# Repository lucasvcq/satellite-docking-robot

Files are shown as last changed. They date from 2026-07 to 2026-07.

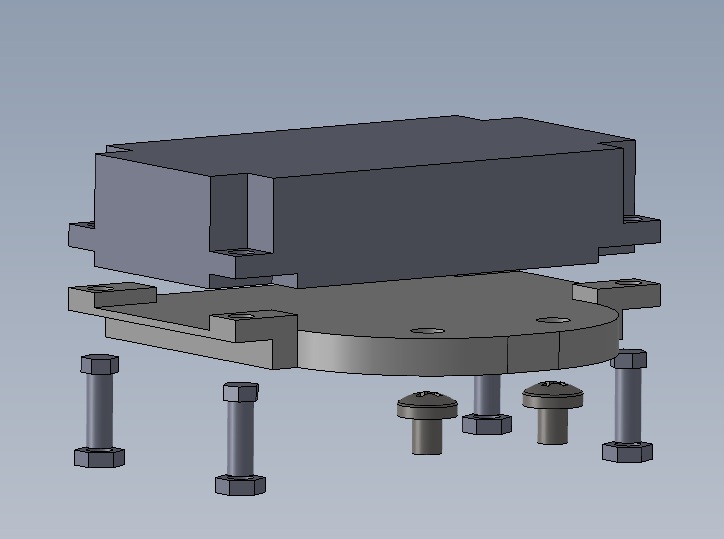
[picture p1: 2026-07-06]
Station Hote/Docking/Final/captures finales/assemblage_convertisseur_vueeclat.PNG

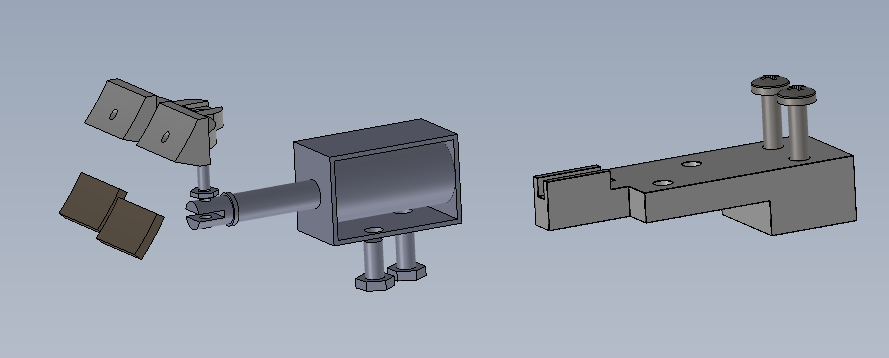
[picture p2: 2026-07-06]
Station Hote/Docking/Final/captures finales/assemblage_finale_vueeclat.PNG

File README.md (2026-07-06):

# Satellite Docking & Filming Robot

A two-part robotic system simulating satellite deployment, inspection, and re-docking — built as a 25-person, one-semester engineering project.

## Overview

The project reproduces a mechanism found on real satellites: a **fixed module** (simulating the main satellite) and a **mobile module** that ejects from it, films the fixed module from the outside using an onboard camera, and then autonomously re-docks.

Team of 25 students over one semester. I was responsible for the **entire software/electronics stack**: code, motor selection, battery selection, camera integration, and wiring.

## My Role

- Full embedded software (Arduino) controlling the mobile module's motors and camera
- Motor selection and sizing for the ejection/return mechanism
- Battery selection (capacity/weight tradeoff for the mobile module)
- Camera integration for the filming sequence
- Full wiring/harness design for the mobile module

## Tech Stack

- **Hardware:** Arduino
- **Domain:** Motor control, embedded C/C++, power budgeting, camera systems

## Key Technical Points

- Coordinating ejection, filming, and return in a single autonomous sequence
- Balancing battery weight vs. flight/operation time on the mobile module
- Wiring reliability on a moving, ejectable platform

## Demo

<!-- Add photos/video of the fixed + mobile module here -->

## Context

School project — ICAM, 2nd year engineering, group project (25 students, 1 semester).

> Note: source code comments, the full project report, and documentation are in French (school requirement). This README provides an English summary of the project.

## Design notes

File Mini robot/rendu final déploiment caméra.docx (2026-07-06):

Rendu final : Partie déploiement de la caméra

Nomenclature

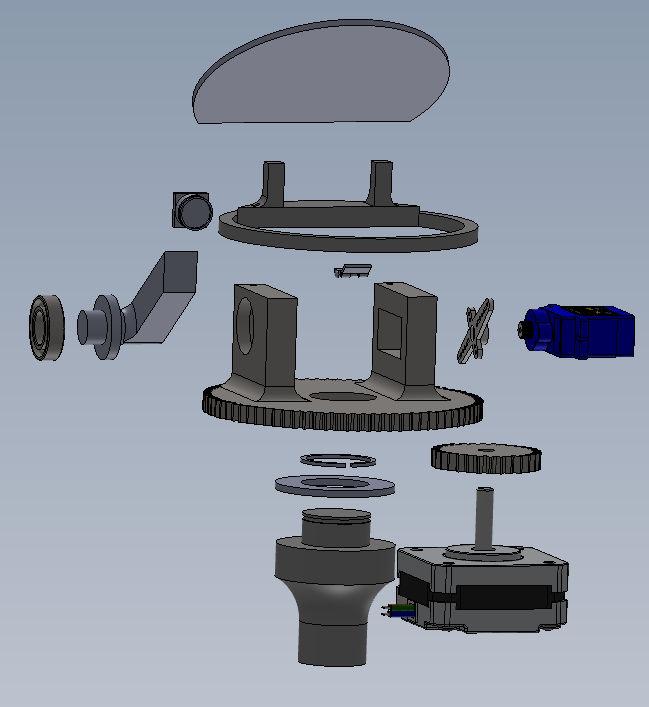
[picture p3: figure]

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
1: Axe chasis | 8 : Couvercle
2 : Roue | 9 : Charnière
3 : Pignon | 10 : Servo moteur
4 : Roulement à bille | 11 : Hélice servomoteur
5 : Caméra | 12 : Butté à aiguille
6 : Bras | 13 : Moteur pas à pas
7 : Support couvercle | 14 : Circlips

Gamme de montage :

Partie déploiement de la caméra
N° étape | Opérations (soudure, taraudage, …) | Schéma, croquis, solidworks

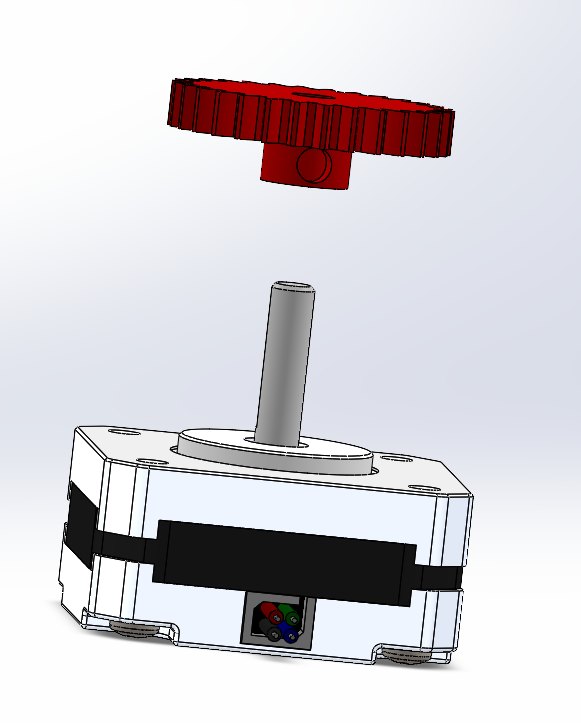
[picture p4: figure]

1 | Placer le pignon sur l’axe du moteur pas à pas

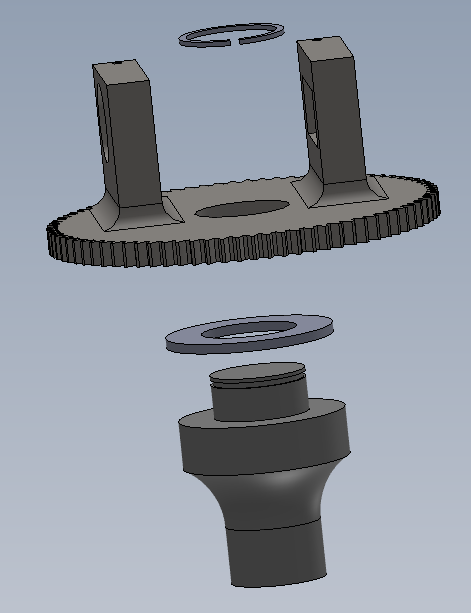
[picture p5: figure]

2 | Placer sur l’axe du châssis la butée à aiguille puis la roue et le circlips

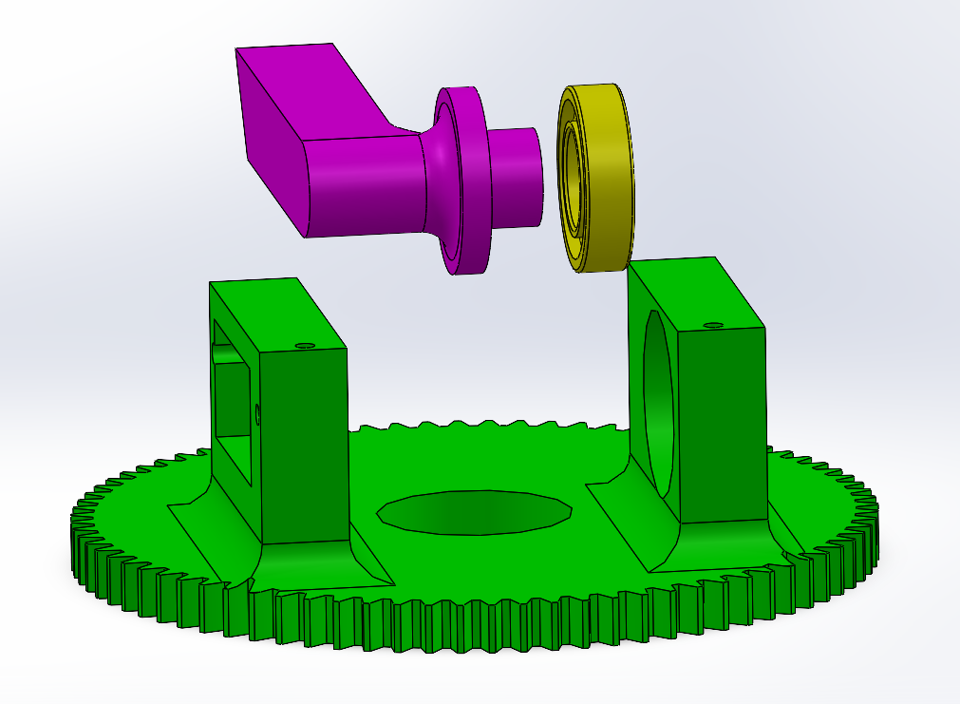
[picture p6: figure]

3 | Placer le roulement et le bras dans le premier socle de la roue | 1 2

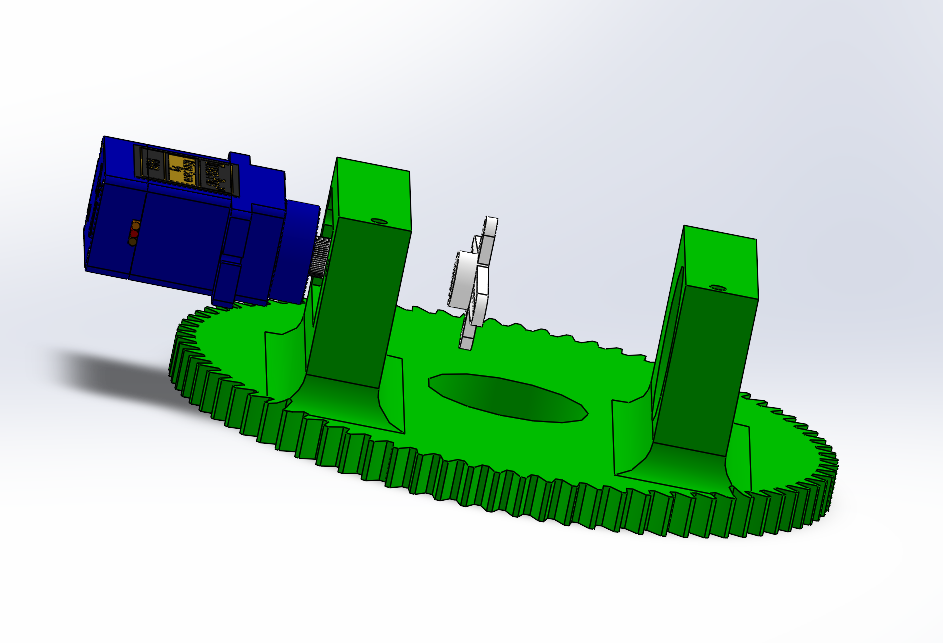
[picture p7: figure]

4 | Placer le servomoteur dans le second socle de la roue | 1 2

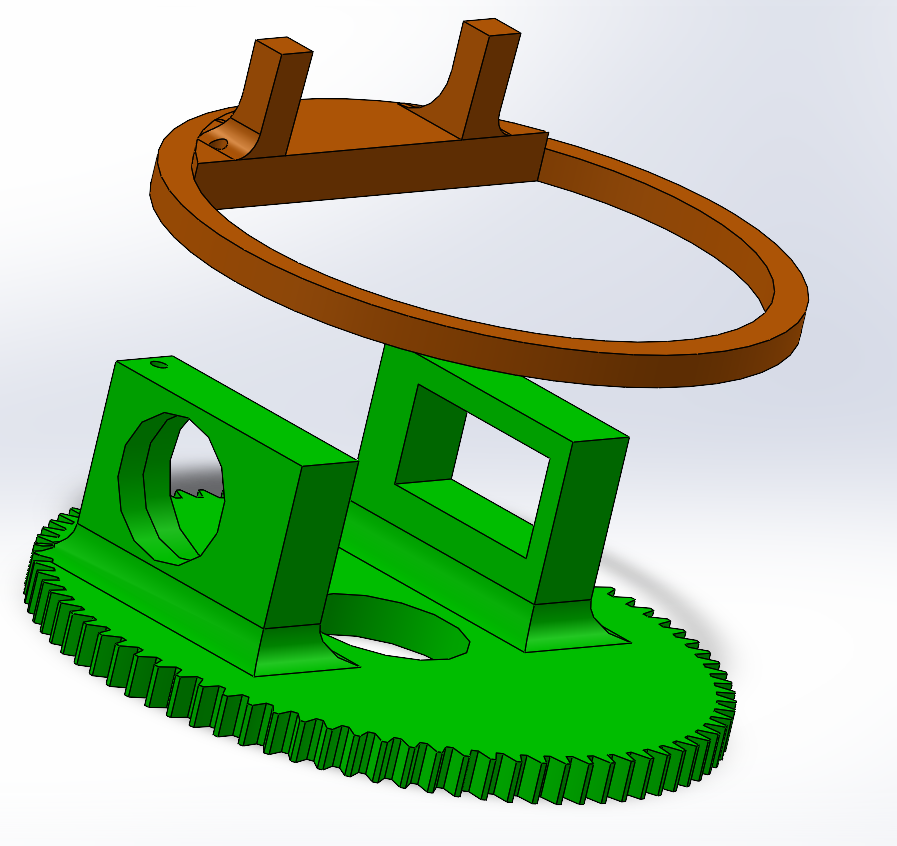
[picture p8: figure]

5 | Visser le support couvercle sur les socle de la roue de chaque côté avec deux vis M2

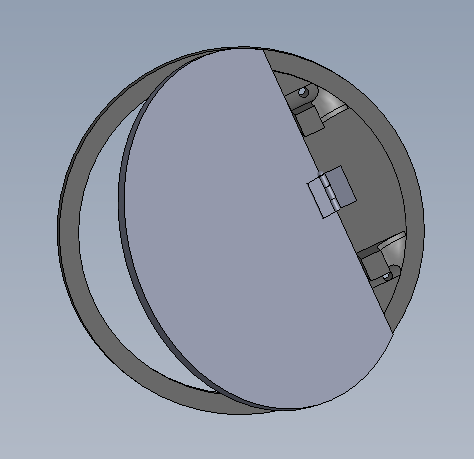
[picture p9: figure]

6 | Clouer la charnière entre les support clapet et le clapet afin d’avoir une liaison pivot

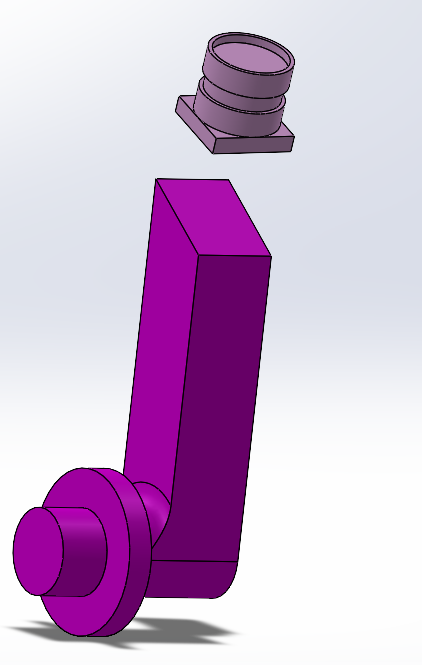
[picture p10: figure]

7 | Collé avec du scotch double face la caméra sur le bout du bras

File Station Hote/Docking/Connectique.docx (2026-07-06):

Fonctionnement :

La station hôte est branchée sur secteur et délivre une certaine énergie. Cette énergie doit être convertie en 12v pour alimenter deux électrodes en nickel qui sont reliés grâce à deux câbles électriques soudé à chacune des électrodes

Problème : comment gérer la connectique et convertir le courant électrique ?

=> Il faut aussi penser qu’il faut alimenter 5 moteurs qui sont sur la station mais eux ne dépendant pas de la batterie;

donc comment les alimenter ?

Ensuite une fois contact entre les 4 électrodes : que faire comme branchement pour que la batterie délivre son énergie aux 4 moteurs du mini robot ?

Est ce que l’on s’aide la carte arduino ?

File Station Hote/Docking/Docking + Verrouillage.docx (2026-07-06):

Docking + Verrouillage

Idées :

-S’inspirer des aspirateurs (aussi tondeuses) autonomes et de la phase de rangement dans leur base rechargeable (car verrouillage et rechargement)

-Même fonctionnement qu’un chargeur par induction magnétique ?

-Technologie QI =>a proximité de l'appareil et du support provoque un champ électromagnétique qui génère du courant

=>l’induction magnétique se produit grâce à une différence de potentiel électrique aux bornes d’un conducteur électrique, donnant naissance à un phénomène électrique

=>La recharge sans fil ou par induction repose sur la loi de l’induction de Faraday (https://fr.wikipedia.org/wiki/Loi_de_Lenz-Faraday) et la loi d’Ampère (https://fr.wikipedia.org/wiki/Th%C3%A9or%C3%A8me_d%27Amp%C3%A8re). Un courant qui circule dans une bobine génère un champ magnétique. On retrouve cette bobine dans la station de recharge. Ce champ magnétique produit une tension dans une deuxième bobine, qui se trouve dans l’appareil même. Cette tension rend possible la circulation du courant dans cette deuxième bobine.

Liens vidéos :

https://youtu.be/eUmNK34zg4w?si=RE0UxOJwnrwsriQn

Liens documents:

-pour la recharge par induction https://www.electronique-mag.com/article10755.html

-exemple de chargeur https://shop.aeg.fr/aspirateurs/aspirateurs-robots/accessoires/socle-de-chargement-du-robot-aspirateur-purei9-rx9-sans-adaptateur/p/4060000710

-mécanisme avec des lamelles de cuivre https://www.robot-maker.com/forum/topic/4003-robot-autonome-se-rechargeant-tout-seul/

-exemple de la brosse à dent https://d-krypton.fr/index.php/technologie/138-technologie/objets/brosse-a-dents/analyse-brosse-a-dents/526-principe-de-fonctionnement-du-chargement

-créer une batterie https://docs.wpilib.org/fr/latest/docs/hardware/hardware-basics/robot-battery.html

https://www.youtube.com/watch?v=eUmNK34zg4w&t=2s lien réparation chargeur aspirateur robot

-transmission d’energie sans fil https://www.youtube.com/watch?v=N0-TR-BpZpw

-lien sur le chargement par contact de charge https://www.vahle.de/fileadmin/cavok_upload/Energie%C3%BCbertragung/Ladekontakte/Ladekontakte/Franz%C3%B6sisch/Cat_10a_fr_Contacts_de_charge.pdf

https://www.youtube.com/watch?v=0F4qeJG9QhU

-dimensionner sa batterie lithium ion https://www.youtube.com/watch?v=PDcdBUG9SnE

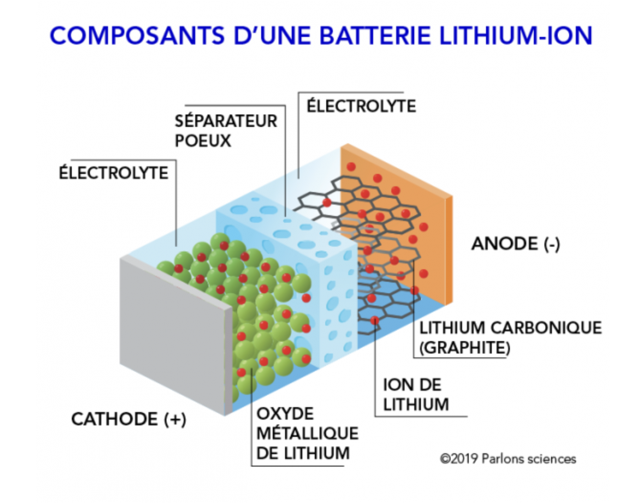
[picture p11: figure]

https://www.webmotoculture.com/station-de-charge-robot-tondeuse-husqvarna/16436-connecteur-charge-robot-tondeuse-husqvarna-group-588950902-7391736256667.html

https://www.webmotoculture.com/station-de-charge-robot-tondeuse-husqvarna/16406-plaque-connexion-charge-robot-tondeuse-husqvarna-574490003-7391736406284.html

https://www.amazon.fr/Lot-anodes-cuivre-pur-galvanoplastie/dp/B07PYNRYX3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

pas le zinc car oxydation donc dégradation de l’électrode

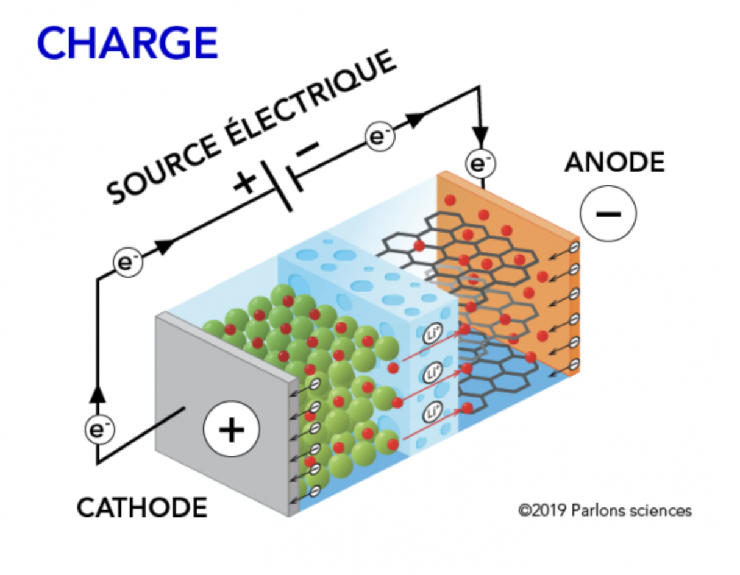
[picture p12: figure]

charge batterie lithium ion

https://passionelectronique.fr/charger-une-batterie-lithium-ion-cccv/#:~:text=Un%20courant%20de%201%2C5,si%20r%C3%A9p%C3%A9t%C3%A9%20dans%20le%20temps)

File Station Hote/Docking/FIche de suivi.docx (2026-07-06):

SUIVIS

Fiche de liens et description plus précise des idées : https://docs.google.com/document/d/11aIBwprFXZhD-TSYb-oCCpfROF9s-JA2nkJWaiH0Sx0/edit?usp=drive_link

DATES | TÂCHES FAITES | TÂCHES/IDÉES EN COURS | A FAIRE
19/12/2023 | -recherche sur quel mode de chargement -technologie qi -où le placer ? | -induction ? -système des robots tondeuses ou de maison | poursuivre les recherches sur le mécanisme de chargement
20/12/2023 | -recherche sur la recharge MIR -fonctionnement batterie lithium | -charger par champ magnétique avec du fil de cuivre mais problème sur le poids donc faire un chargement par contact entre électrode | poursuivre les recherches sur le mécanisme de chargement

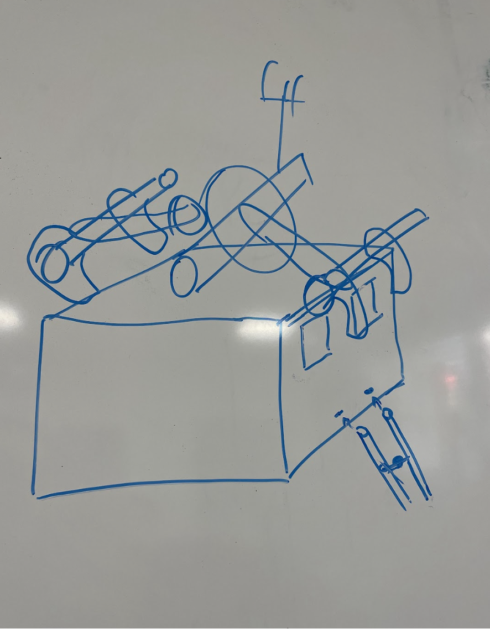
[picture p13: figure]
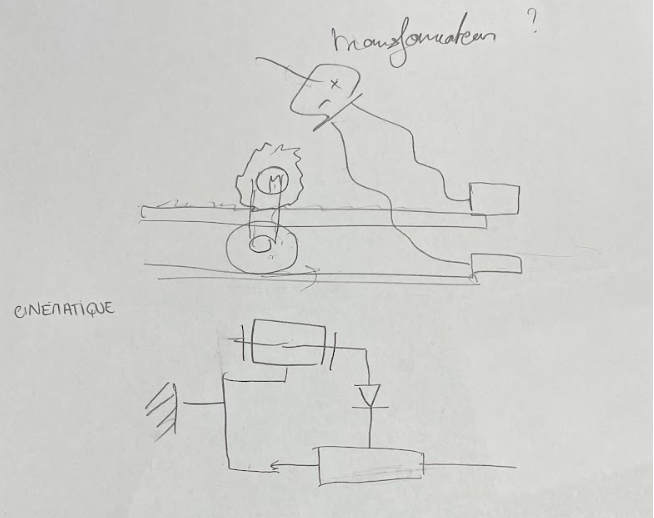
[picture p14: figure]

17/01/2024 | -recherche sur les batteries au nickel - besoin d’un transformateur | -la charge s’enclenche en même temps que le verrouillage par système de pignon crémaillère alimenté par un moteur pas à pas - seconde méthode : par un ressort lié aux pinces | -schéma cinématique du mécanisme - calculer quel type de transformateur utilisé -calculer la pression à appliquer sur les plaques de nickel -calcul du couple moteur nécessaire
24/01/2024 | -début de la rédaction pour la jalon avec les avantages et les inconvénients de toutes les solutions qui ont pu être envisagées https://docs.google.com/document/d/1Y-hJFDyKSYLCWOa0ryIylMQf1yoepxAHz28kI_ejrlM/edit?usp=drive_link | -réalisation de tous les schémas cinématiques pour les différentes solutions | -poursuivre les recherches - calculer quel type de transformateur utilisé -calculer la pression à appliquer sur les plaques de nickel -calcul du couple moteur nécessaire -continuer la rédaction -mettre au propre les schémas
31/01/2024 | -poursuite de la rédaction du jalon | -finir les schémas + continuer de s’informer https://knowhow.distrelec.com/fr/automatisation/alimentation-et-mouvement-des-robots-comment-fonctionnent-les-robots/ | -terminer l’écriture du jalon -commencer le solidwork
28/02 | choix du solénoïde à commander + calculs avec la partie commande Idée : mettre un isolant au bout de la tige du solénoïde, dont l’épaisseur diminue facilement afin que le moteur ne subisse pas de force de pression + impression d’une pièce en PLA pour renforcer l’isolation et protéger la tige | -solidworks du solénoïde + écriture du jalon 2 | -poursuivre l'écriture du jalon 2 + finir solidworks + commander les matériaux
04/03 | solidworks + récap avec mr rodriguez | solidworks + connectique | solidworks + choix de l’isolant et des électrodes
06/03

Lucas RODRIGUEZ Noémie HEMAR

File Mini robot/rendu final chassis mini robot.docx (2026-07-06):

Présentation Générale:

Contexte

Depuis plusieurs années, les classes préparatoires PT de l’ICAM Toulouse réalisent un projet

durant le second semestre. Le but de ce projet étant de mettre en pratique toutes les compétences

pratiques et théoriques étudiées pendant ces 2 ans. L’objectif de cette année 2024 est de réaliser et

d’automatiser un robot spatial télépiloté. Celui-ci sera composé d’une station hôte et d’un mini robot

qui sera capable de filmer un satellite dans l’espace.

Le projet a été lancé le 19 décembre 2023, il s'accompagnera de différents jalons et s'achèvera par une

présentation orale le 31 mai 2023.

b) Objectifs du projet

L’objectif principal de ce projet est de créer un robot capable de réaliser une vidéo de son

satellite afin d’y diagnostiquer les éventuels dommages. Les images produites pourront être utilisées

pour des projets extérieurs.

Le robot devra respecter un cahier des charges précis et devra s’adapter à toutes ses contraintes

environnementales et économiques.

Ce projet permet une étude de dimensionnement, de conception, de réalisation et

d'automatisation, il concrétise l’ensemble de nos connaissances théoriques et nous permet d’avoir une

meilleure vision du métier d’ingénieur.

Le jalon 1 a pour objectif de reprendre l’ensemble du travail réalisé lors de ces premières semaines et

notamment de détailler les solutions envisagées et retenues pour chaque sous-partie.

c) Cahier des charges

Dans le cadre de notre projet, l’espace sera modélisé par une plaque de téflon.

Ce mini robot SPACE INSPECTOR sera composé de deux modules :

- La station hôte

- Le mini robot

Ses actions seront les suivantes:

Le mini-robot s'éjecte de la station, il glisse sur la plaque, réalise ses différents plans et retourne à la

station. Il se verrouille et se recharge jusqu’à sa prochaine utilisation.

Icam, site de Toulouse 75 avenue de Grande Bretagne CS 97615 31300

Toulouse cedex 3

+33 5 34 50 50 50 icam.fr SIRET 399 252 154 000

48

Enseignement supérieur et recherche | Services aux entreprises | Formation professionnelle

3

Le mini-robot sera relié à sa station hôte grâce à un câble (fil d'Ariane) d’une longueur de 1,5 à 2 mètres,

ceci pour assurer sa sécurité et pour ne pas endommager le satellite.

Station hôte

La station hôte ne doit pas dépasser les dimensions maximales d’un cube d'arête 10 pouces c’est à dire

de 25,4 cm.

Elle contiendra le mini robot pendant la phase de décollage et sera composée d’un treuil qui permettra

son retour ainsi que d'un système de verrouillage et de déverrouillage.

Mini-robot

Le mini-robot est considéré comme le corps du robot, il devra se ranger dans sa station hôte lors du

décollage et à la fin de chaque prise de vue. Il se compose d’une caméra capable de se ranger

entièrement et de se déployer à chaque utilisation. La masse du robot ne doit pas excéder 1,5 kg.

Icam, site de Toulouse 75 avenue de Grande Bretagne CS 97615 31300

Toulouse cedex 3

+33 5 34 50 50 50 icam.fr SIRET 399 252 154 000

48

Enseignement supérieur et recherche | Services aux entreprises | Formation professionnelle

4

d) Organisation générale

Pour réaliser ce projet notre promotion a été répartie en quatre groupes suivant sa classe et son

ordre alphabétique. Nous sommes le groupe PTB-B.

Dans notre groupe, les différents élèves ont été répartis ainsi: certains s’occupent de la partie mini-

robot, d’autres de la station hôte et ceux qui restent de l’électronique ( docking et commande).

La répartition générale du groupe a été faite par nos professeurs. Deux chefs de projets ainsi que deux

chefs de partie ont été désignés : l’un pour le mini robot et l’autre pour la station hôte. Chaque membre

du groupe a été rattaché à une sous-partie en fonction de ses compétences.

D’un point de vue organisation, nous avons fait le choix de mettre en place des fiches de suivi par sous-

partie. A chaque fin de séance, chaque groupe énumère ce qu’il a fait durant la séance, ce qu’il ont

commencé à faire et ce qu’il prévoit de faire pour les prochaines séances. De cette manière les chefs ont

une trace du travail de chacun.

Nous avons également désigné un chef de salle, un chef d’imprimante et un chef d’achat.

Le budget maximal pour ce projet s'élève à 500 euros.

Mini robot

1/ Présentation partie et cahier des charges:

Le mini robot doit être pris en compte dans la station hôte pour se recharger et aura la mission de prendre des prises de vue pour permettre le transfert d’image vers la Terre. Ses dimensions devront donc correspondre à celles de la station hôte en ayant un poids le plus restreint possible afin que celui- ci puisse s'éjecter . Équipé d'une caméra, il pourra déployer cette dernière via une commande au sol utilisant un joystick.

La masse totale du mini robot (hors station hôte, câble et treuil) ne devra pas dépasser 1,5 kg. De plus, il reste toujours attaché à la station hôte par un câble, permettant de le ramener à l'aide d'un treuil.

Les principales exigences que nous nous sommes fixées pour le mini robot sont la solidité, la facilité de fabrication et enfin un mini robot peu onéreux.

Tout d’abord, la première idée, pour la conception de ce mini robot, était de prendre des plaques que l’on allait fixer ensemble afin de former un parallélépipède rectangle de hauteur 10 cm, de longueur 15 cm et de largeur 12 cm. Cependant après avoir discuté avec les chefs de projet, nous en avons conclu qu’il y allait avoir de grandes chances que celui-ci ne puisse pas se loger dans la station hôte à cause de sa forme rectangulaire, et qu’il suffirait d’un simple décalage lors de sa phase de treuillage pour bloquer tout le système.

C’est pour cela que nous avons choisi une autre solution, que nous allons vous détailler ci-dessous.

2/ Solution retenue + mise en place

-châssis:

Premièrement, à la suite de plusieurs idées de conception, en prenant les avantages de chaque solutions, et bien sur en regardant les inconvénients, nous avons décidé de réaliser notre mini robot sur un point primordial, la facilité d'insertion du mini robot dans la station hôte, qui sera essentiel pour le fonctionnement du système global

C’est pour cela que nous avons choisi de réaliser une forme cylindrique avec une tête sphérique qui se limite à ces dimensions : hauteur : 10 cm, de longueur 15 cm et de largeur : 12 cm.

Nous avons simplifié au maximum le châssis en le conservant en une seule pièce, que l’on séparera ensuite en deux parties, pour avoir une difficulté de conception et d’assemblage moins importante.

De plus ce châssis sera modelé en fonction des systèmes qu’il accueillera, avec la création de support depuis le châssis, pour fixer chacun de ses composants

Ensuite, pour refermer le mini robot, nous allons attacher son toit avec une mise en position(MIP) grâce à leurs faces et un maintien en position (MAP) grâce à deux vices et deux écrous.

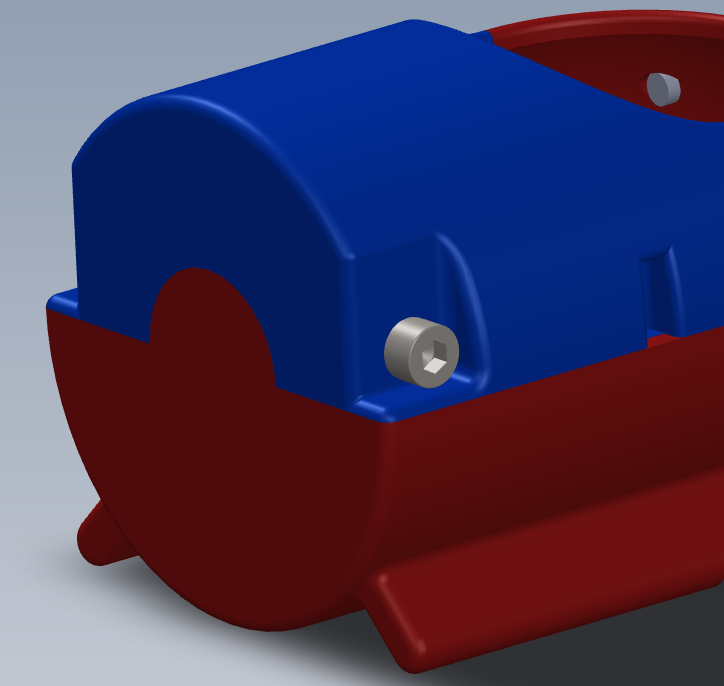
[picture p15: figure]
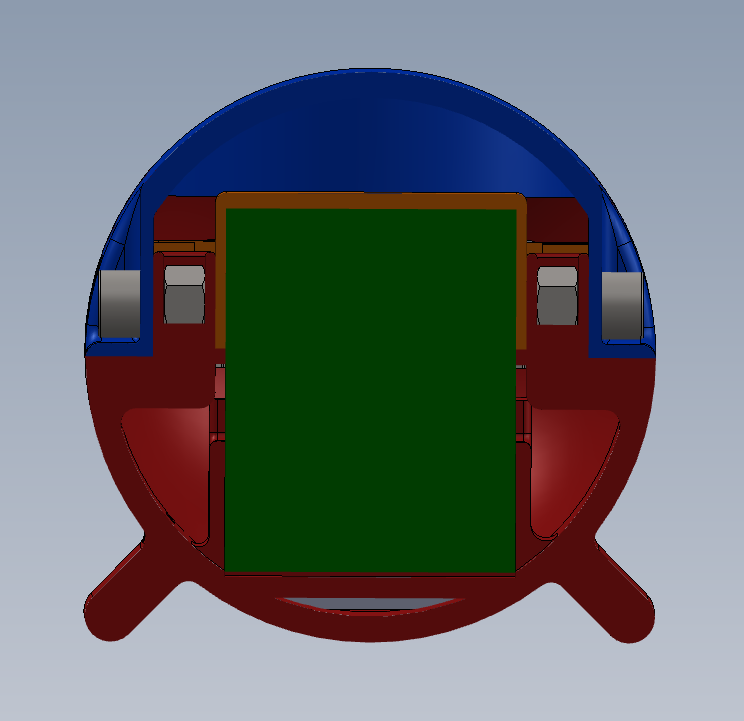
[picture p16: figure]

-Les Matériaux utilisés :

Nous avons réalisé toutes nos différentes pièces, que ce soit la base de notre châssis ou encore les différents supports, à l'imprimante 3D avec le filament de type PLA. Ce matériau assurera la résistance de notre mini robot et nous permettra de facilement usiner notre solution.

Ensuite, concernant les vis nous avons utilisé des vis M3 pour fixer tous nos différents supports, puis des vis M8 pour fixer le toit de notre mini robot à sa base. Puis pour assurer une bonne fixation nous avons rajouté des écrous de taille M3 ou M8

## -Modèle du châssis extérieur pour la structure complète du robot :

Dans notre solution, nous retrouvons deux encoches qu’ils maintiennent le mini robot lors de son entrée dans la station hôte. Puis, nous avons trois pions dans lesquels nous allons enrouler le câble du treuil, puis que nous allons encastrer sur la face droite de notre mini robot permettant d’avoir une bonne prise de celui-ci. Sur le côté, nous avons l’emplacement des deux électrodes qui peut alimenter le système et permettent au mini robot de se recharger. Ensuite nous retrouvons deux patins sur la partie inférieure du châssis afin de le stabiliser et cela facilitera le glissement.

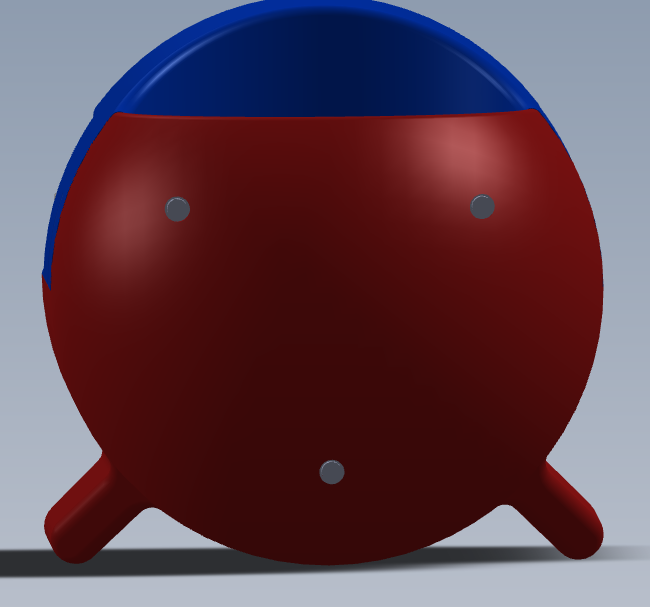
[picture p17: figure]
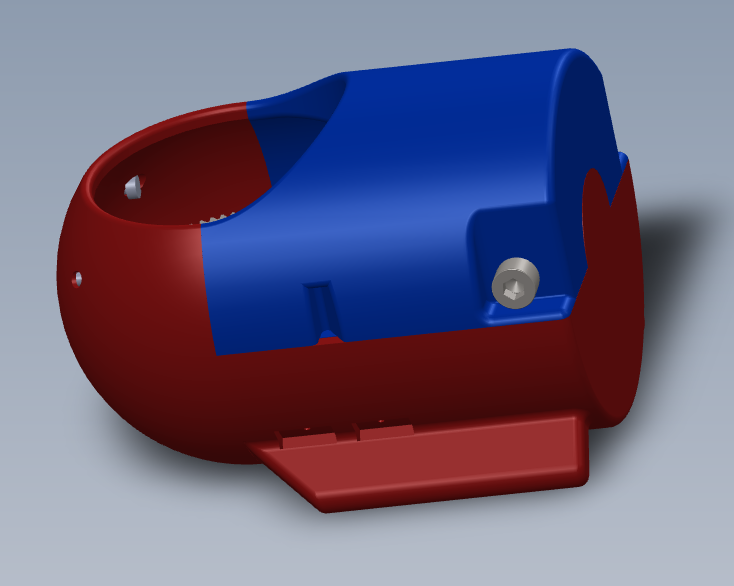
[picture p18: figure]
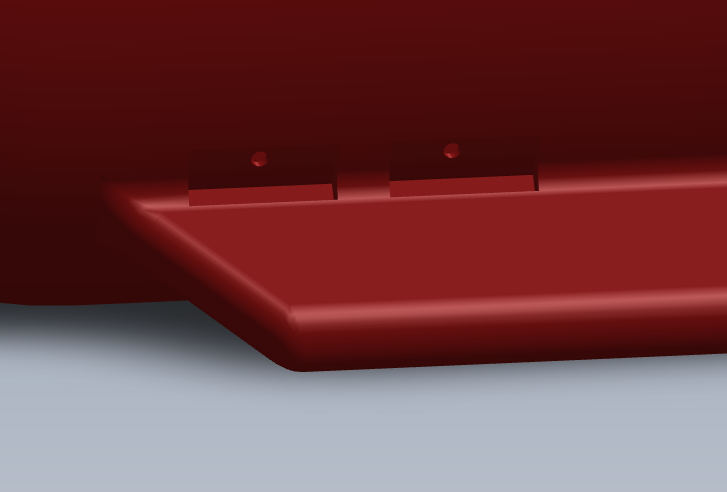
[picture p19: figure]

## -Ouverture:

Ensuite, concernant l’ouverture du châssis haut nous avons réalisé, à l'imprimante 3D, un clapet anti retour en forme de cercle de diamètre 8 cm. Il permet de protéger la caméra tout en réduisant le poids et sera facile à installer. Pour réaliser le basculement du couvercle nous avons simplement visser une charnière, comme vous pouvez le voir ci-dessous.La caméra, lors de son déploiement, poussera le clapet qui se lèvera et lors de son rangement il se baissera tout seul. Lors du déploiement la caméra poussera le clapet lui offrant une grande vision, puis lors de son rangement le clapet se refermera tout seul.

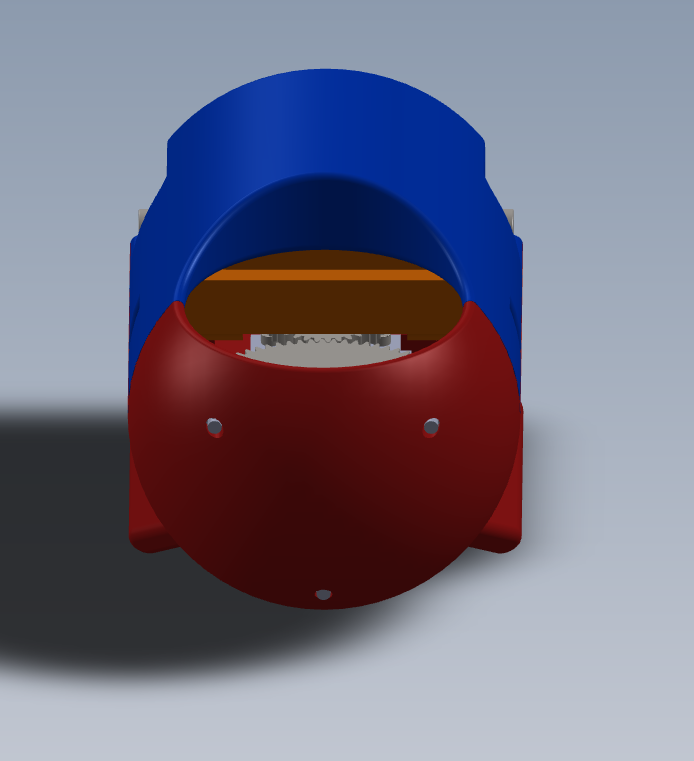
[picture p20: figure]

-Modèle du châssis intérieur pour la structure complète :

Dans notre solution, nous avons le module esp32 de la caméra, la carte de prototypage qui contrôle les différents moteurs, puis,le système de déploiement de la caméra et la batterie. Nous retrouverons aussi tous les différents supports qui viendront maintenir ces composants.

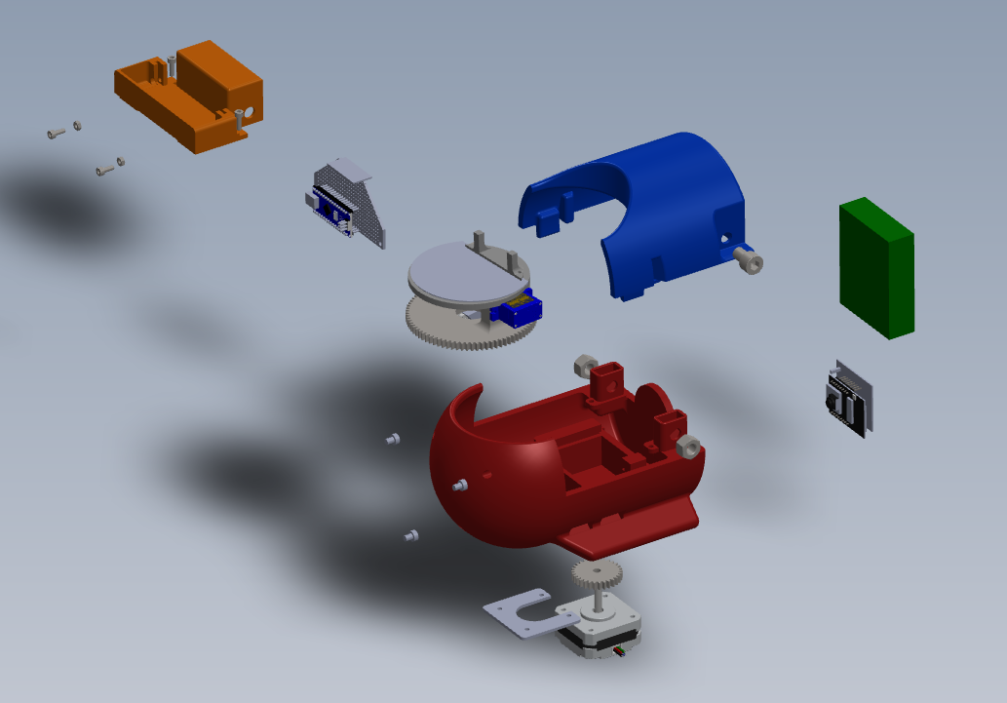
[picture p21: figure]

3/ Problèmes rencontrés et solutions

Avantages : Cette structure serait très facile à assembler et solide car elle est seulement composée que de deux pièces. De plus, cette solution n’aura aucun problème pour rentrer dans la station hôte grâce à sa tête sphérique.

Inconvénients : L'inconvénient principale de cette solution est qu'elle ne permet pas de faire des modifications s' il y a des soucis lors de la conception car nous avons une place très restreinte à l'intérieur du mini robot. En plus de cela, elle va demander un temps de fabrication assez conséquent.

Problèmes et solutions :

- réussir à faire rentrer tous les composants dans le mini robot
- diminuer au maximum la taille du mini robot afin qu’il puisse se loger dans la station hôte
- Nous avons mis au début un seul anneau sur la face avant du mini robot mais nous avons vu à l'aide de test que le robot, lors de la traction du treuil, se balançait et pourrait bloquer sa rentrée dans la station hôte. C’est pourquoi nous avons pensé à mettre en place le système avec trois pion afin d’avoir un bonne prise du mini robot
- nous avons eu des problèmes avec les cables car nous avons vu que avec la carte de prototypage et la caméra il fallait trouver une place pour les faire passer dans notre mini ronot

Solution générale:

En conclusion nous avons passé beaucoup de temps sur solidworks à modifier la tailles des différents composants afin que tout puisse se loger dans le mini robot. Nous avons très vite eu l’idée eu l’idée de faire de faire une première impression du châssis du mini robot, afin d’identifier les différents problèmes de conception du à ça taille très restreinte, ce qui nous a permis d’avancer pas à pas en modifiant les pièces au fur et mesure pour que tout s’imbriquent parfaitement et en gagnant le maximum de place.

Autres:

-Schéma cinématique mini robot:

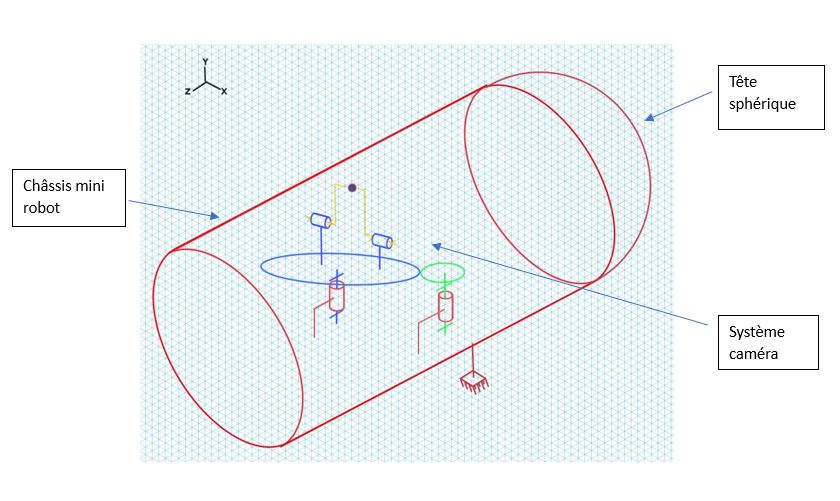
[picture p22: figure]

-Gamme de montage :

N° étape | Opérations (soudure, taraudage, …) | Schéma, croquis, solidworks

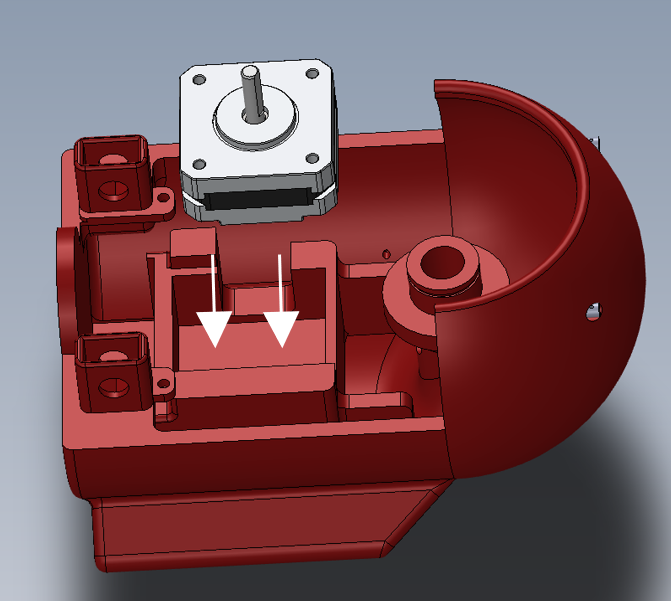
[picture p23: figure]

1 | Prendre la partie bas du châssis et placer le moteur pas à pas dans son emplacement

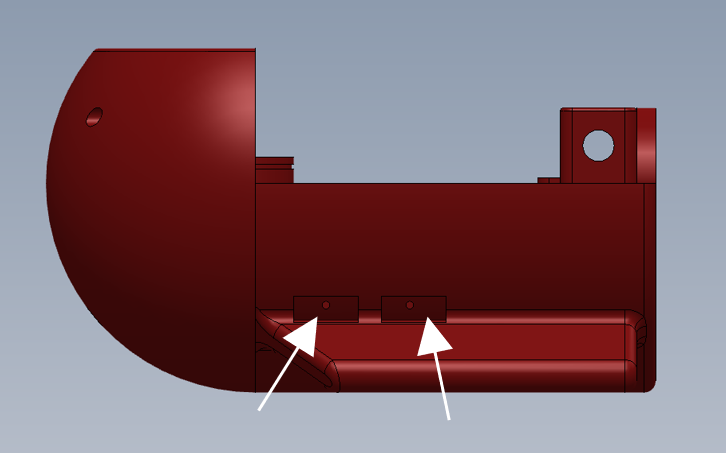
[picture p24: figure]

2 | Placer les électrodes à leurs places respectives

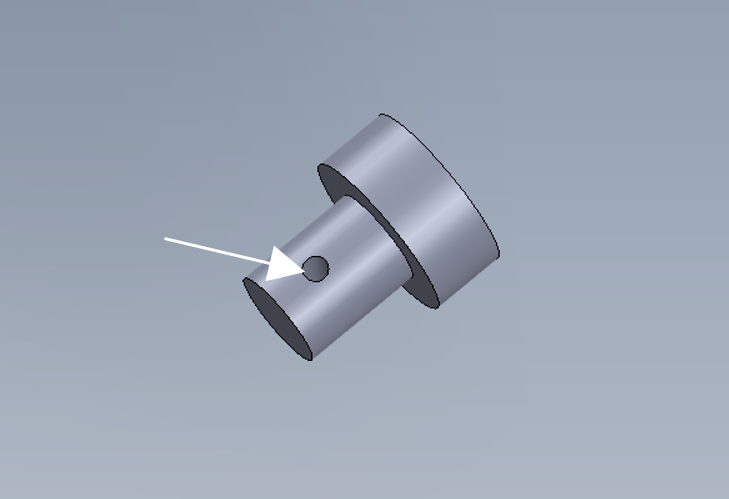
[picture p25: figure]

3 | Prendre le fil du treuil et faire un noeud autour de chaques pions
4 | Encastrer les 3 anneaux,directement dans le châssis

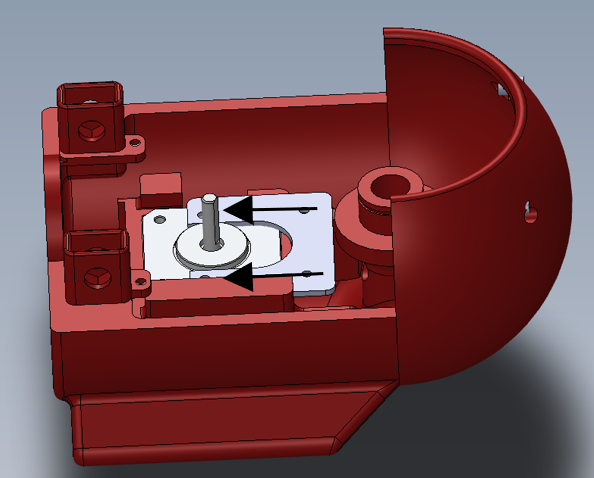
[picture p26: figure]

5 | Placer la plaque qui viendra bloquer le moteur pas à pas et la visser avec 4 vis de diamètre 3 mm


6 | Visser la plaque avec 4 vis de diamètre 3 mm


7 | Placer le module esp 32 de la caméra avec son support


8 | Placer le pignon sur l’axe du moteur pas à pas


9 | Placer le système de caméra sur l’axe du châssis


10 | Mettre la batterie à son emplacement


14 | Visser son couvercle avec deux vis de diamètre 3 mm et de deux écrous


12 | Insérer la carte de prototypage


13 | Verrouiller la carte à l’aide de deux vis de diamètre 3 mm et de deux écrous


14 | Placer le châssis haut sur le châssis bas afin de fermer le robot la visser avec deux vis de diamètre 8 mm et ses boulons

Nomenclature :


1: châssis bas | 7 : Batterie
2 : châssis haut | 8 : carte de prototypage
3 : moteur pas à pas | 9 : support carte de prototypage
4 : plaque (support moteur) | 10 : module caméra esp32 avec son support
5 : pignon | 11 : pions
6 : système caméra

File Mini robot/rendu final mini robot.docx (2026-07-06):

rendu final mini robot

nomenclature:

Gamme de montage :

Partie mini robot
N° étape | Opérations (soudure, taraudage, …) | Schéma, croquis, solidworks


1 | Prendre la partie bas du châssis et placer le moteur pas à pas dans son emplacement


2 | Placer le pignon sur l’axe du moteur pas à pas


3 | Placer sur l’axe avec un épaulement du châssis bas la butée à aiguille puis la roue et le circlips


4 | Placer le roulement et le bras dans le premier socle de la roue | 1 2


5 | Placer le servomoteur dans le second socle de la roue | 1 2


6 | Visser le support couvercle sur les socle de la roue de chaque côté avec deux vis de diamètre M2


7 | Clouer la charnière entre les support clapet et le clapet afin d’avoir une liaison pivot


8 | Collé avec du scotch double face la caméra sur le bout du bras


9 | mettre la batterie puis visser son couvercle avec deux vis de diamètre 4 mm
10 | insérer la carte de prototypages
11 | placer le cache de la plaque de prototypage afin de protéger les câbles


12 | placer le châssis haut sur le châssis bas afin de fermer le robot la visser avec deux vis de diamètre 6 mm et ses boulons
13 | placer les deux électrodes


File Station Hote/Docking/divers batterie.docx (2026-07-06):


choix d’electrodes


https://fr.aliexpress.com/item/1005005652738294.html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,scm-url:1007.40000.327270.0,pvid:93ebbf17-09de-4c7a-8013-ba4026c8d7f2,tpp_buckets:668%232846%238111%231996&pdp_npi=4%40dis%21EUR%212.90%210.49%21%21%2122.12%213.73%21%40211b617a17069785410205563ed12e%2112000033895913581%21rec%21FR%21%21AB&utparam-url=scene%3ApcDetailTopMoreOtherSeller%7Cquery_from%3A&search_p4p_id=202402030842210684180786807887908647_2

isolant


https://fr.aliexpress.com/item/1005005850378507.html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,scm-url:1007.40000.326746.0,pvid:3229bbeb-f918-4b03-a76d-1be9c16ab99a,tpp_buckets:668%232846%238111%23472&pdp_npi=4%40dis%21EUR%211.71%210.49%21%21%211.82%210.53%21%402103854017069791498925819e0110%2112000034570935919%21rec%21FR%21%21AB&utparam-url=scene%3ApcDetailBottomMoreOtherSeller%7Cquery_from%3A

https://floordirekt.fr/products/gummiplatten-aus-sbr-gummi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

OK https://www.amazon.fr/ACIT-n%C3%A9opr%C3%A8ne-caoutchouc-polyur%C3%A9thane-%C3%A9paisseur/dp/B0BBRPN3B2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

OK

https://www.amazon.fr/Lot-anodes-cuivre-pur-galvanoplastie/dp/B07PYNRYX3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

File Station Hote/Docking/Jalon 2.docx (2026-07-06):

La solution finale choisie est la recharge par contact entre électrodes conductrices. Le matériau privilégié est le cuivre car il possède le meilleur rendement coût-efficacité.

Par rapport aux autres systèmes choisis, nous devons éviter que les électrodes gênent le système d'éjection du robot. Pour cela nous avons réfléchi à deux solutions.

Afin d’effectuer le contact entre les électrodes placées sur le mini-robot et les deux autres présentes sur la station hôte, nous avions tout d’abord pensé à la création d’un système pignon crémaillère. Celui-ci aurait été alimenté par un moteur pas à pas par exemple. Les électrodes seraient donc placées sur le système et bougeraient en avançant le long de la crémaillère. Le moteur et le courant transmis par les électrodes seraient alors alimentés par la batterie.


x

y

z

Cependant cette idée à rapidement été abandonnée car elle est complexe à réaliser, énergivore et prendrait trop de place inutilement au sein de la station hôte.

En restant sur le principe de pouvoir approcher et écarter les électrodes pour que le contact déclenchant le chargement soit créé, une seconde solution a été envisagée : mettre un moteur solénoïde. Ce petit moteur réalise une simple translation de 8 mm de course. Il ne prend pas beaucoup de place et ne consomme pas beaucoup d’énergie lors de son fonctionnement. Les deux électrodes sont placées à l’extrémité de son axe et la charge est dépendante de l’enclenchement de la translation. Il y aurait donc deux électrodes + , - , placées sur une même face latérale du mini-robot afin que nous puissions nous servir seulement d'un moteur solénoïde. Pour la réalisation de l’assemblage du robot, nous les avons modélisés sur solidworks ainsi que tout le système de charge.

- Moteur solénoïde


Ci-dessus se trouve le moteur solénoïde. Étant donné que nous allons l’acheter, le mécanisme de translation a été représenté de manière grossière mais toutes les cotes et éléments clés ont été dessinés. On remarque que dans la cage du moteur, 2 trous taraudés sont déjà présents ce qui nous permettras de plus facilement fixer le moteur à la station. De plus, l’axe est percé et il y a un espace pour insérer une éventuelle pièce. Nous avons profité de cet espace pour créer un support capable de venir se glisser à travers cette fente, et de réaliser le maintien des électrodes.

Plusieurs modélisations ont été faites :

- Première conception du support pour les électrodes :


Nous avons choisi d’utiliser la géométrie de l’axe du moteur solénoïde car il nous offre une très bonne solution pour emboîter notre support. Dans un premier temps, nous avons créé un capuchon qui viendrait se mettre dans l’encoche de l’axe du moteur puis à l’aide d’une goupille, nous le bloquons sur celui-ci. Nous avons réduit les surfaces des parties de gauche et de droite par souci de gâchis de matière. Mais, la création de ce capuchon gêne dans l’usage des trous déjà présents (soucis d'alignement parfait des trous qui est trop complexe à réaliser suite aux imprécisions de l'imprimante et de l'usinage).

- Deuxième conception du support pour les électrodes :


Nous avons donc décidé de choisir cette représentation finale pour notre support des électrodes. Nous avons enlevé le cylindre qui allait causer des soucis d’usinage mais nous avons laissé “le pavé” avec le trou qui permettra l’assemblage des deux pièces. Nous avons aussi annulé l’enlèvement de matière pour ajouter de la solidité car le gâchis potentiel reste moins important que la solidité de notre pièce. La matière utilisée est du plastique PLA, utilisé dans nos imprimantes 3D, et qui permettrait aussi d’isoler le moteur de tout courant électrique.

- Assemblage final :


Cuivre Isolant

Cette conception finale semble être la plus adaptée. Nous avons réussi à enlever un maximum de matière tout en conservant la solidité grâce à l'élimination des angles droit. On a aussi modélisé deux électrodes de cuivre et un isolant d’une épaisseur d'environ 3 mm qui servirait à réduire la force exercée par le moteur. En effet, lorsque le contact entre une électrode du mini-robot et une électrode de la station est fait, il ne faut pas que la pression exercée soit trop importante sous peine d'abîmer tout le mécanisme.

De plus, l’utilisation d’isolant semble être importante au sein du robot. En effet, la station hôte étant faite majoritairement en profilé aluminium nous voulons éviter tout possible court-circuit.

Au niveau du choix de la batterie, les recherches ont été effectuées en travaillant avec la partie commande. Il se sont chargés des calculs de dimensionnement et nous, de la connectique afin de savoir si le modèle se rechargeait plus ou moins facilement. A ce stade du projet, le modèle envisagé pour assurer l’autonomie du mini-robot est celui ci : modèle Accu Li-Ion MGL9073


L’avantage de ce modèle est qu’il n’est pas très lourd (143 g) et est de dimension acceptable (70x56x19mm). Elle sera positionnée sur l'arrière du mini-robot et, étant certainement le poids lourd du mini-robot, elle sera positionnée le plus proche du sol possible.

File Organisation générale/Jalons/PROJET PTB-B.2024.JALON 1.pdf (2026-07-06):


Icam, site de Toulouse | 75 avenue de Grande Bretagne | CS 97615 | 31300
Toulouse cedex 3
+33 5 34 50 50 50 | icam.fr | SIRET 399 252 154 000
Enseignement supérieur et recherche | Services aux entreprises | Formation professionnelle
Projet ICAM PTB-B | 2023-2024

# Jalon 1

# Projet Space Inspector

Icam, site de Toulouse | 75 avenue de Grande Bretagne | CS 97615 | 31300
Toulouse cedex 3

1

## SOMMAIRE

Icam, site de Toulouse | 75 avenue de Grande Bretagne | CS 97615 | 31300

2

# I) Présentation Générale:

### a) Contexte

Depuis plusieurs années, les classes préparatoires PT de l’ICAM Toulouse réalisent un projet durant le second semestre. Le but de ce projet étant de mettre en pratique toutes les compétences pratiques et théoriques étudiées pendant ces 2 ans. L’objectif de cette année 2024 est de réaliser et d’automatiser un robot spatial télépiloté. Celui-ci sera composé d’une station hôte et d’un mini robot qui sera capable de filmer un satellite dans l’espace.

Le projet a été lancé le 19 décembre 2023, il s'accompagnera de différents jalons et s'achèvera par une présentation orale le 31 mai 2023.

### b) Objectifs du projet

L’objectif principal de ce projet est de créer un robot capable de réaliser une vidéo de son satellite afin d’y diagnostiquer les éventuels dommages. Les images produites pourront être utilisées pour des projets extérieurs.
Le robot devra respecter un cahier des charges précis et devra s’adapter à toutes ses contraintes environnementales et économiques.
Ce projet permet une étude de dimensionnement, de conception, de réalisation et d'automatisation, il concrétise l’ensemble de nos connaissances théoriques et nous permet d’avoir une meilleure vision du métier d’ingénieur.
Le jalon 1 a pour objectif de reprendre l’ensemble du travail réalisé lors de ces premières semaines et notamment de détailler les solutions envisagées et retenues pour chaque sous-partie.

### c) Cahier des charges

Dans le cadre de notre projet, l’espace sera modélisé par une plaque de téflon.

Ce mini robot SPACE INSPECTOR sera composé de deux modules :
- La station hôte
- Le mini robot

Ses actions seront les suivantes:

Le mini-robot s'éjecte de la station, il glisse sur la plaque, réalise ses différents plans et retourne à la station. Il se verrouille et se recharge jusqu’à sa prochaine utilisation.


Icam, site de Toulouse | 75 avenue de Grande Bretagne | CS 97615 | 31300

3

Le mini-robot sera relié à sa station hôte grâce à un câble (fil d'Ariane) d’une longueur de 1,5 à 2 mètres, ceci pour assurer sa sécurité et pour ne pas endommager le satellite.

Station hôte

La station hôte ne doit pas dépasser les dimensions maximales d’un cube d'arête 10 pouces c’est à dire de 25,4 cm.

Elle contiendra le mini robot pendant la phase de décollage et sera composée d’un treuil qui permettra son retour ainsi que d'un système de verrouillage et de déverrouillage.

Mini-robot

Le mini-robot est considéré comme le corps du robot, il devra se ranger dans sa station hôte lors du décollage et à la fin de chaque prise de vue. Il se compose d’une caméra capable de se ranger entièrement et de se déployer à chaque utilisation. La masse du robot ne doit pas excéder 1,5 kg.

Icam, site de Toulouse | 75 avenue de Grande Bretagne | CS 97615 | 31300

4

### d) Organisation générale

Pour réaliser ce projet notre promotion a été répartie en quatre groupes suivant sa classe et son ordre alphabétique. Nous sommes le groupe PTB-B.
Dans notre groupe, les différents élèves ont été répartis ainsi: certains s’occupent de la partie mini-robot, d’autres de la station hôte et ceux qui restent de l’électronique ( docking et commande).

La répartition générale du groupe a été faite par nos professeurs. Deux chefs de projets ainsi que deux chefs de partie ont été désignés : l’un pour le mini robot et l’autre pour la station hôte. Chaque membre du groupe a été rattaché à une sous-partie en fonction de ses compétences.

D’un point de vue organisation, nous avons fait le choix de mettre en place des fiches de suivi par sous-partie. A chaque fin de séance, chaque groupe énumère ce qu’il a fait durant la séance, ce qu’il ont commencé à faire et ce qu’il prévoit de faire pour les prochaines séances. De cette manière les chefs ont une trace du travail de chacun.

Nous avons également désigné un chef de salle, un chef d’imprimante et un chef d’achat.

Le budget maximal pour ce projet s'élève à 500 euros.

### e) Procédures

Durant ces premières semaines de travail, nous nous sommes concentrés sur la recherche de solutions. En effet, à la lecture du cahier de charges, nous avons eu quelques problèmes pour visualiser et concevoir des solutions. Chaque groupe a alors proposé un certain nombre de solutions réalisables ou non à partir du cahier des charges et des contraintes mécaniques et spatiales.
Pour chaque solution proposée, nous avons réalisé des dessins techniques mais aussi des schémas cinématiques pour tenter au mieux de les définir. Puis nous avons fait des modélisations sous

Icam, site de Toulouse | 75 avenue de Grande Bretagne | CS 97615 | 31300

5

SolidWorks et rédigé des explications. Enfin, pour accompagner ces idées nous avons pu réaliser quelques essais pratiques afin de valider ou non certains modèles et nous aider dans le choix des solutions.
Ces recherches de solutions ont été assez délicates puisqu’il fallait, à partir d’une idée générale du robot, trouver des solutions adaptées pour chaque système. En plus, nous avons pris un léger retard sur les parties châssis pour trouver la forme et les dimensions optimales du mini robot.

# II) Mini-robot

### a) Châssis

Le mini-robot est conçu pour s'intégrer parfaitement à la station hôte. Il a besoin d’un logement durant le décollage et entre chaque session de prises de vue pour se recharger.

Le mini-robot est doté d'une caméra qui peut être déployée à l'aide d'une commande au sol via un joystick et qui permet le transfert des images vers la Terre. La masse maximale du robot, sans la station hôte, le câble et le treuil, est de 1,5 kg. Il doit de plus rester connecté à son satellite hôte via un câble pour être ramené à la station par le treuil.

Pour parvenir à cette conception, nous avons d’abord sélectionné les caractéristiques en tenant compte du système de la caméra et de son déploiement puis nous avons travaillé en collaboration avec les responsables de la station hôte pour agencer le treuil, la batterie et les autres composants de manière optimale. L'objectif étant de maximiser l'espace disponible pour le mini-robot tout en garantissant une solution robuste et réalisable.

A. Première solution

La première solution est d’utiliser un châssis de la forme d’un parallélépipède rectangle de hauteur 10 cm, de longueur 15 cm et de largeur 12 cm.

| Caractéristiques | Avantages | Inconvénients
Solution 1 | Parallélépipède rectangle: -hauteur : 10 cm -longueur : 15 cm -largeur : 12 cm | Facilité de conception | Bloqué si sa position bouge pendant le lancement

Icam, site de Toulouse | 75 avenue de Grande Bretagne | CS 97615 | 31300

6

Avantages

Cette structure permet d’assurer la solidité du mini-robot pour un coût moindre. De plus, la conception de cette forme sera facile et pourra facilement prendre en compte le système de caméra à l’intérieur. Sa forme permet d'adapter plusieurs situations et nous laisse une marge de sécurité en cas de problèmes à l'intérieur pour placer les composants.

Inconvénients

L’inconvénient de cette solution est son rangement dans la station hôte. En effet, lors de la propulsion du mini-robot, il est possible qu’il bouge et qu’il reste bloqué à l’intérieur ou qu’il n’arrive pas à entrer dans la station hôte.

Matériaux

Matériaux | Avantages | Inconvénients
Bois | -Résistant lors de la propulsion - Facile à usiner | - Masse -Usure
Plexiglas | -Facilite le glissement et la propulsion | -Risque de déformation
Armature avec plaque en aluminium | -Léger -Maniable | -Risque de déformation -Coût
B. Seconde solution

La deuxième solution est de réaliser une forme cylindrique avec une tête sphérique qui se limite à ces dimensions : hauteur : 10 cm, de longueur 15 cm et de largeur : 12 cm.

| Caractéristiques | Matériau | Avantages | Inconvénients
Solution 2 | Cylindre avec une tête sphérique | Plastique (Imprimante 3D) | -Facilite l’entrée dans la station hôte | -Conception de la forme sphérique difficile -Solidité -Perte de place


Icam, site de Toulouse | 75 avenue de Grande Bretagne | CS 97615 | 31300

7

Avantages

Cette structure permet de faciliter l’entrée dans la station hôte même s’il y a rotation du mini-robot lors de la propulsion.

Inconvénients

L’inconvénient principal de cette solution est la conception de cette structure avec des formes complexes à assembler et à réaliser qui rend le système moins solide. De plus, cette forme de châssis limite la place intérieure et ne permet pas de faire des modifications (usinage) s' il y a des soucis lors de la conception.

Nous avons deux possibilités en ce qui concerne le matériaux pour le cœur de notre châssis (la pièce en noir ci-dessus). Pour toutes les pièces se rattachant au cœur elles seront faites à l'imprimante 3D donc en plastique.

Matériaux pour le cœur du châssis

Matériaux | Avantages | Inconvénients
Bois | -Possibilité de modifier la pièce une fois usiner afin de l’ajuster (facile à usiner) -Résistant | -Masse -Usure
Impression 3d | -Résistant -Faciliter à usiner | -Temps d’usinage - Modification une fois usiner - Quantité de filament utilisé
C. Troisième solution

La troisième solution est une copie conforme de la seconde. La seule différence est que pour celle-ci on simplifie au maximum le châssis en le conservant en une seule pièce que l’on sépare ensuite en deux parties.

| Caractéristiques | Matériaux | Avantages | Inconvénients
Solution 3 | Cylindre avec une tête sphérique | Plastique (Imprimante 3D) | -Facilite l’entrée dans la station hôte -Rapidité d’assemblage | -Conception de la forme sphérique -Solidité -Perte de place -Temps de fabrication


Icam, site de Toulouse | 75 avenue de Grande Bretagne | CS 97615 | 31300

8

Avantages

Cette structure serait très facile à assembler et plus solide que la précédente n’étant composée que de deux pièces. De plus cette solution n’aura aucun problème pour rentrer dans la station hôte grâce à sa tête sphérique.

Inconvénients

L'inconvénient principale de cette solution est qu'elle ne permet pas de faire des modifications (usinage) s'il y a des soucis lors de la conception. De plus, elle va demander un temps de fabrication assez conséquent.

Matériaux

Nous avons deux possibilités en ce qui concerne le matériaux pour le coeur de notre chassis (la pièce en noir ci-dessous). Pour toutes les pièces se rattachant au cœur, elles seront faites à l'imprimante 3D.

Matériaux | Avantages | Inconvénients
Bois | -Possibilité de modifier la pièce une fois usiner afin de l’ajuster (facile à usiner) -Résistant | -Masse -Usure
Impression 3d | -Résistant -Faciliter à usiner | -Temps d’usinage - Modification une fois usiner - Quantité de filament utilisé
D. Système de redressement

Ce système apparaît à partir de la deuxième solution afin de redresser le robot et de le maintenir dans une certaine position sur la terre.

Le système est composé d’un moteur relié directement à un réducteur et à deux pâles.

Ce système permet de plier et déplier ses deux pâles qui permettront au mini-robot de se placer à l’horizontale après son lancement. Ce système est essentiel sur Terre afin d’avoir la meilleure position possible pour filmer le satellite avec la caméra.


Icam, site de Toulouse | 75 avenue de Grande Bretagne | CS 97615 | 31300

9

E. Ouverture du toit

Nous avons ensuite deux solutions concernant le déploiement de la caméra :

Caractéristiques | Matériaux | Avantages | Inconvénients | Photos
Anti-retour clapet Cercle | Plastique Silicone Caoutchouc | - Installation rapide - Réduction de la masse | -Ouverture lors de la projection -Basculement du clapet qui empêcherait sa fermeture
Ouverture cylindrique | Aucun | - Facilité de construction - Grande vision lors de la sortie de la caméra | - Protection de la caméra

Conclusion

En conclusion, les caractéristiques du mini-robot ont été choisies pour garantir son intégration à la station hôte. Nous avons opté pour la troisième solution, résultat d'un processus de sélection où sa faculté à rentrer dans la station hôte et son mécanisme de déploiement ont dicté le positionnement des autres composants. En collaboration étroite avec les responsables de la station hôte, nous avons soigneusement agencé le treuil, la batterie et les autres éléments pour optimiser l'espace disponible tout en assurant la robustesse et la faisabilité du projet. Cette approche stratégique nous laisse confiants quant à la performance et à l'efficacité du mini-robot dans l'accomplissement de sa mission spatiale.

### b) Déploiement de la caméra

Notre partie consiste à trouver un mécanisme qui permettra de déployer une caméra lorsque la phase d'éjection du mini-robot sera effectuée. Le cahier des charges nous impose certaines contraintes :

- La caméra doit être protégée à l'intérieur du robot lors des phases d'éjection et de rétraction.
- La caméra doit pouvoir filmer sur deux axes avec un angle minimum de 45° par axe.
- Notre mécanisme doit rentrer dans les dimensions de notre mini-robot.

Nous avons donc trouvé trois solutions différentes qui ont chacune leurs avantages et inconvénients.

Icam, site de Toulouse | 75 avenue de Grande Bretagne | CS 97615 | 31300

10

A. Première solution

La première solution s'inspire des mécanismes utilisés dans les chars d'assaut. Le système est composé de deux parties. La première partie comprend une roue dentée [1] reliée à un pignon [2] qui sera entraîné en rotation par un moteur pas à pas permettant ainsi une rotation de 360°. Deux supports encastrés sur la roue maintiennent l’axe sur lequel est encastré l’arc de cercle denté [3]. Deux roulements à billes permettent de le guider en rotation. Un moteur pas à pas entraine le pignon [4] qui engrène avec l’arc de cercle denté. Sur celui-ci est placée la caméra [5] suivant une inclinaison définie

| Caractéristiques | Avantages | Inconvénients | Schéma cinématique
Solution 1 | Rotation d’une demi-roue dentée | Pas de contrepoids rotation verticale de 360° | Déploiement faible de la caméra
Solution 2 | Bras articulé | Grand déploiement de la caméra Rotation verticale de 360° | Risque de basculement
Solution 3 | Bras simple sur un disque rotatif | Le système a besoin de peu d’espace | A besoin d’un couple (plus) important pour se déployer à l'extérieur

Icam, site de Toulouse | 75 avenue de Grande Bretagne | CS 97615 | 31300

11

qui permet lors du déploiement de la caméra d’avoir un champ de vision maximal. Si la caméra n’est pas inclinée, la rotation du bras doit être plus élevée pour que le toit du robot n'apparaisse pas dans le champ de vision de la caméra

La position initiale du système est lorsque la partie plane de l’arc de cercle est parallèle au toit du robot où est placé un clapet permettant de sortir la caméra. Lorsque l’arc de cercle est mis en mouvement, il se développe verticalement poussant le clapet qui s’ouvre sous la poussée de l’arc de cercle. Ce système permet donc d’avoir le toit du robot toujours fermé en position initiale. Nous avons choisi des moteurs pas à pas car ils ont un couple élevé lorsque leur vitesse est lente, ce qui permet de réaliser les deux rotations du système.

Avantages

C’est un système solide où il n'y a pas de contrepoids et qui permet d’avoir les deux rotations dans deux axes différents en utilisant deux moteurs pas à pas.

Inconvénients

Avec ce système, il y a un risque que la caméra ne se déploie pas assez haut et donc de ne pas avoir un


champ de vision maximal.

B. Seconde solution

Icam, site de Toulouse | 75 avenue de Grande Bretagne | CS 97615 | 31300

12

Cette solution implique l'utilisation d'un disque mis en mouvement grâce à un système d'engrenage. Ce système est composé d'une roue dentée [2] connectée au moteur et d'un pignon [1] fixé sur le premier axe de rotation, permettant d'augmenter le rapport de réduction afin d'obtenir un mouvement du bras supérieur [4] à 180°. Nous avons choisi un rapport de réduction de 2, ce qui nous permet d'atteindre une rotation de 360° .
(R = (Ze / Zs) = (20/10) = 2).

Le bras est équipé de deux articulations orientées dans la même direction:

La première articulation (a) se situe au niveau du socle, elle est assurée par un servomoteur qui crée une liaison pivot entre la première partie du bras et la deuxième partie du bras. De plus, deux roulements à billes à contact oblique facilitent la rotation du premier axe. Cela nous permet de réaliser une rotation de 180° de notre premier bras. Nous utilisons des servomoteurs dont le couple est de 10kg/cm, notre deuxième bras mesurant 7.8 cm notre servomoteur peut soulever 1.28 kg.

La seconde articulation (b) s’effectue sur la deuxième partie du bras. Son mouvement est engendré par deux servomoteurs qui seront directement vissés sur le deuxième bras. A l'extrémité de ces bras est fixée la caméra.
Nous utilisons pour ce système des servomoteurs dont le couple est de 1.6 kg/cm , notre deuxième bras mesurant 2.7 cm, nos servomoteurs pourront soulever 0.59kg x 2 donc 1.18 kg. Nous avons choisi des servomoteurs car ils sont plus légers que les moteurs pas à pas qui nous permettent de limiter le contrepoids dans ce système. Dans cette solution, le bras sera plié dans le robot lors de la phase d'éjection et de rétraction afin de protéger la caméra dans le robot. Puis le bras pourra être déployé quand le robot sera à l'arrêt.

Avantages

Il permet d’avoir une grande amplitude de mouvements ainsi qu’une manipulation du bras avec grande précision.

Inconvénients

Nous utilisons quatre servomoteurs, dont deux au bout du bras qui risquent de le faire basculer . Mais aussi un code pour la phase de repliement qui sera plus compliqué que la première solution.


Icam, site de Toulouse | 75 avenue de Grande Bretagne | CS 97615 | 31300

13

C. Troisième solution

Cette troisième solution est constituée d’un système d'engrenage permettant une rotation de 180° sur l’axe vertical. Un moteur pas à pas permet la rotation du pignon [1] qui va entraîner en rotation la roue [2], celle-ci est positionnée sur un axe vertical encastré au bâti. Pour cet engrenage il y aura un rapport de réduction de 2 avec la roue. Celle-ci est composée de 40 dents et le pignon de 20 dents.
Deux supports [3] sont placés sur cette roue, ces deux supports contiennent deux roulement à billes à contact oblique permettant d’avoir une liaison pivot avec le bras où est encastrée la caméra [4]. Ce bras sera mis en mouvement grâce à un servomoteur de 1.6 Kg/cm directement vissé au bras. En effet notre bras mesurant 8 cm notre servomoteur pourra soulever 0.2 kg
Nous avons mis un moteur pas à pas pour la rotation du pignon car grâce à son couple élevé, il permet de réaliser la rotation de la roue. Pour la rotation du bras, nous avons choisi un servomoteur car il est léger et de petite taille, ce qui permet de le placer plus facilement et il ajoute peu de masse à notre système.

Lors de la phase d'éjection et de rétraction, le système sera en position initiale. Cela consiste à ce que le bras soit parallèle à la roue et ainsi de protéger la caméra. Celle-ci est placée sur le bras et aura une inclinaison précise qui permet lors du déploiement de ne pas voir le toit du robot sur la vidéo. La caméra placée sur le bras aura une certaine inclinaison qui lui permet lors du déploiement de devoir moins lever le bras pour sortir la caméra. En effet, si la caméra est fixée à plat sur le bras du robot, l'objectif de la caméra filmera une partie du toit du robot or avec une même inclinaison du bras lorsque que l’on incline la caméra, cela permet que l'objectif ne filme presque plus le toit du robot.

Avantages
Ce système permet un grand déploiement de la caméra tout en préservant sa protection , et il offre également un avantage en termes d'optimisation de l'espace occupé.

Inconvénients
Le bras aura besoin d’un couple suffisamment élevé afin de pouvoir se déployer tout en ouvrant le clapet.

Icam, site de Toulouse | 75 avenue de Grande Bretagne | CS 97615 | 31300

14

### c) Transmission et pilotage

A. Choix de la caméra

Notre objectif est de sélectionner une caméra offrant une qualité d'image optimale tout en respectant notre budget. Pour ce faire, nous avons entrepris des recherches sur différents types de caméras afin d'évaluer leurs avantages et leurs inconvénients respectifs.

ESP-32 CAM
Cette caméra offre une multitude d'avantages qui répondent parfaitement aux exigences de notre robot et à nos besoins spécifiques. En premier lieu, la connectivité Wi-Fi ou Bluetooth nous permettra non seulement d'accéder aux images à distance mais également de la contrôler à distance.

De plus, elle se distingue par sa qualité d'image exceptionnelle, garantissant des captures nettes et détaillées. De plus, la présence d'une LED intégrée nous permet de capturer des images même dans des conditions de faible luminosité, ce qui élargit considérablement les possibilités d'utilisation de la caméra notamment dans des environnements nocturnes ou peu éclairés.

CAM PIXY 2

Cette seconde caméra, nous a été prêté par l'un de nos professeurs. Nous avons dans un premier temps vérifié la qualité d’image, qui s'est révélée insatisfaisante. En effet, après avoir examiné les spécifications techniques, nous avons constaté qu'elle fonctionnait à une cadence de seulement 6 images par seconde. Il est important de noter qu'une cadence minimale de 16 images par seconde est nécessaire pour obtenir une bonne fluidité de mouvement.

Caméra | Images | Avantages | Inconvénients
ESP-32 CAM | | -bluetooth+Wi-fi - masse: 10g - bonne qualité d’image: 15 images par seconde - Prix: 14.99€ | - nécessite une rallonge pour gagner de l’espace
CAM PIXY 2 | | -masse: 10g | -Prix: 70.99€ - qualité moyenne: 6 images par secondes - bluetooth et Wi-fi non intégrés - La caméra doit rester fixée au module

Icam, site de Toulouse | 75 avenue de Grande Bretagne | CS 97615 | 31300

15

De plus, les dimensions de la caméra n'étaient pas adaptées à nos besoins. En effet, le module n’est pas fixé à celle-ci, ce qui prend beaucoup d’espace au niveau du bras. En outre, le prix de cette caméra dépasse largement le budget alloué selon les directives du cahier des charges.

Conclusion

Nous avons fait le choix de prendre la ESP-32 CAM, une décision motivée par une analyse attentive de ses caractéristiques et de ses performances car elle présente beaucoup plus d’avantages que la CAM PIXY 2 et avec un très bon rapport qualité prix.

B. Pilotage

Notre objectif est de piloter les différents moteurs orientant la caméra. Le robot étant inhabité, nous ne pouvons pas utiliser de système filaire. Un système d'émetteur-récepteur est donc obligatoire. En outre, pour envoyer la commande à l’émetteur, nous sommes libres sur le système utilisé. On peut piloter depuis l’ordinateur via une interface, utiliser des boutons poussoirs ou encore un joystick.

Système | Images | Avantages | Inconvénients
Module Radio émetteur récepteur 433 MHz | | Faible coût (9 €) Matériel très utilisé et documenté | Nécessite la création d’une “manette” de commande et deux cartes Arduino
Module Bluetooth HC-05 | | Faible coût (9 €) Utilisation d’une seule carte arduino | Nécessite l’utilisation d’un téléphone en bluetooth

Module Radio émetteur récepteur 433 MHz

Ce module utilise des radios fréquences et a une portée de quelques mètres pouvant être augmentée en branchant une antenne si besoin. On trouve une grande quantité de “tutos” divers et variés sur internet expliquant comment l’utiliser et le code arduino n’est pas excessivement complexe. Cependant, nous devons utiliser 2 cartes arduinos: une sur le mini-robot avec le récepteur et une sur la manette de commande avec l'émetteur.


Icam, site de Toulouse | 75 avenue de Grande Bretagne | CS 97615 | 31300

16

Module Bluetooth HC-05

Ce module utilise le bluetooth. On le branche sur la carte arduino reliée aux moteurs et le connecte en bluetooth au téléphone. Via une application disponible sur le playstore, on peut utiliser une interface ressemblant à une manette pour envoyer des informations au module. Ces infos permettent ainsi de piloter les moteurs orientant la caméra.

Manette de commande

La manette de commande est composée d’un joystick et de boutons poussoirs servant à commander les moteurs. Nous avons déjà réussi à commander un moteur avec le joystick et nous avons commencé à réaliser des tests afin d’en utiliser deux en même temps.

Conclusion

On a choisi d’utiliser le module radio émetteur récepteur 433 MHz pour une question de praticité. En effet, nous ne voulons pas être dépendant d’une application tiers dans cette partie et voulons développer nous-même la manette

C. Branchement:

Pour bien piloter la caméra on aura besoin de 2 servomoteurs ainsi que d’un joystick.

Icam, site de Toulouse | 75 avenue de Grande Bretagne | CS 97615 | 31300

17

# III) Station hôte

### a) Châssis

L' objectif principal de la station hôte est d'accueillir le mini-robot ainsi que différents systèmes nécessaires à son bon fonctionnement comme le système de recharge ou de propulsion.
La mission ici va être de comprendre le fonctionnement de ces différents mécanismes dans le but de les intégrer spatialement dans la station hôte. L’étanchéité est aussi à prendre en compte car c’est un facteur non négligeable au bon fonctionnement de l’ensemble du système.
En se référant au cahier des charges, la station hôte doit :

❖ Accueillir le mini robot, ainsi que les systèmes de docking, verrouillage, éjection et le treuil.

❖ Accueillir l’ensemble des circuits électriques

❖ Respecter les contraintes environnementales.

❖ Respecter les dimensions imposées (cube de 10 pouces).

A. Première solution

La première solution consiste à utiliser deux plaques de tôles en aluminium, pliées en forme de “U” de manière à ce qu’une fois assemblées, elles forment un cube, en ayant au préalable percé un trou sur l’une de ses faces latérales pour accueillir le mini-robot.

| Caractéristiques | Matériaux | Avantages | Inconvénients | Photos
Solution 1 | 2 tôles assemblées entre elles. (220x220x220) mm avec une épaisseur entre 1 mm et 2 mm | Aluminium | -Robustesse -Personnalisation des ouvertures -Coût | - Difficulté de maintenance - Complexité de la conception

Icam, site de Toulouse | 75 avenue de Grande Bretagne | CS 97615 | 31300

18

Avantages

La structure réalisée avec les tôles va permettre d’obtenir une structure robuste et résistante, qui protègera efficacement les composants internes de la station hôte. De plus la tôle peut être facilement modulable, ce qui nous permet de faire des ouvertures sur mesure et réaliser le passage du mini-robot.
Enfin le prix de la tôle est lui moindre, ce qui est son principal atout.

Inconvénients

On rencontre plusieurs inconvénients pour cette solution. La première difficulté est celle de la maintenance. En effet, l’accès aux composants internes sera peu pratique à cause de ses deux seules parties distinctes. Ce qui rend plus difficile la réalisation des opérations de maintenance, installation, etc.
La production de ces deux plaques est complexe à réaliser, ce qui entraîne des coûts de production.

On voit ici, grâce à la modélisation, qu’il est peu pratique d’utiliser cette structure à cause du peu d'accès qu’elle offre. En conclusion, la facilité et le coût des matériaux ne peuvent pas compenser le peu de praticité, nous n’avons donc pas retenu cette solution.

B. Deuxième solution

La deuxième solution consiste à utiliser des profilés pour faire la structure de la station hôte. Son utilisation permet de rendre les systèmes internes plus facile à manipuler. Les dimensions des fixations profilées seraient de 3 x 10 x 220 mm. Cette structure propose légèreté et solidité.

| Caractéristiques | Matériaux | Avantages | Inconvénients | Photos
Solution 2 | Châssis hôte: 250 x 250 x 250 mm 3 x 10 x 250 mm | Aluminium | - Modularité - Facilité d’assemblage | -Coût -Rigidité limitée - Limitation de charge


Icam, site de Toulouse | 75 avenue de Grande Bretagne | CS 97615 | 31300

19

Avantages

Le système est modulable ce qui va faciliter l'organisation des composants internes au châssis notamment lors du montage ou de la maintenance du robot.
Ce système permet de positionner des systèmes où l’on souhaite de façon très pratique. De plus, la géométrie de ces profilés permet d’optimiser son poids.

Inconvénients

Les profilés sont souvent plus chers que la tôle. De plus, la rigidité est moins importante que les plaques de tôle en raison de leur petite section sur leur hauteur. On peut aussi noter que les profilés manquent de rigidité structurelle, ce qui peut compromettre la rigidité du châssis, ce qui nous empêcherait d’y appliquer des efforts intenses.

C. Troisième solution (solution finale)

La troisième solution consiste à reprendre la deuxième en mettant des profilés plus épais pour augmenter la rigidité de l’ensemble. Les dimensions de chaque arête du châssis seraient donc réalisées avec des profilés de 10x10x250 mm.

| Caractéristiques | Matériaux | Avantage | Inconvénients | Photos
Solution 3 | Châssis hôte: 250 x 250 x 250 mm 10 x 10 x 250 mm | Aluminium | -Robustesse -Facilité d’assemblage -Coût | -Encombrant


Icam, site de Toulouse | 75 avenue de Grande Bretagne | CS 97615 | 31300

20

Avantages

Ce système ressemble fortement au système précédent cependant il propose plus d'avantages.
Un de ses points forts est son rapport entre rigidité et masse, important lors des
chocs et vibrations que peut subir la structure. De plus, le coût du profilé classique
est moindre comparé à un profilé mieux travaillé. Un autre avantage clé des profilés en aluminium réside dans leur facilité d’assemblage.

Inconvénients

Malgré le fait que cette solution propose plein d'avantages, elle présente aussi certains inconvénients qui sont à prendre en considération. Bien que l’alliage en aluminium soit relativement léger, il reste plus lourd que certains polymères ou composites. Les profilés en aluminium peuvent être moins résistants aux contraintes mécaniques par rapport à certains matériaux plus robustes comme le titane ou d’autre alliage fait pour l’espace.

Pour réaliser cette solution, nous avons décidé d’utiliser des connecteurs modulables pour joindre les profilés entre eux :

Ci-dessous, une modélisation des différents éléments composant le mini-robot en cotation réelle afin de se rendre compte de l’espace nécessaire et donc de la taille du châssis.

Nous avons envisagé de créer différents niveaux et sections à l’intérieur de la station hôte afin d’optimiser la place.

- Panneaux en aluminium : surface extérieure étanche.
- Panneaux composites en aluminium : léger et résistant
- Pour étanchéifier le châssis on va pouvoir utiliser des joints d’étanchéité en caoutchouc ou des joints en silicones entre les panneaux et les profilés


Icam, site de Toulouse | 75 avenue de Grande Bretagne | CS 97615 | 31300

21

D. Choix des matériaux
Nous avons choisi l’alliage d’aluminium pour sa résistance physique et sa résistance à la corrosion (exemple: 6060 ou 7075)
Finalement, nous avons choisi l’alliage d’aluminium 6060 puisqu’il est plus résistant et moins cher.
E. Conclusion

Au vue des trois solutions et après réflexions, la troisième solution a été retenue pour des raisons de robustesse, coûts et modulabilité. C’est la solution qui nous semble la plus adaptée puisque les profilés sont assez utilisés et fiables dans le milieu industriel. Pour les matériaux des différentes faces et niveaux, nous avons choisi un alliage d’aluminium qui propose une bonne résistance et de la légèreté.

### b) Treuil et système d'éjection

La partie éjection consiste à lancer le robot à l’extérieur de la station hôte. La partie treuil doit commander l'enroulement et le déroulement du câble pendant la phase de retour du robot. Ces deux fonctions sont complémentaires et leur association permet une optimisation de la place occupée. De plus, la partie éjection ne pourrait pas fonctionner sans que le treuil ramène le robot à l'intérieur de la station. D’après le cahier des charges, la vitesse d’enroulement minimale du câble est de l'ordre de 5 mm/s, la masse du mini robot ne devra pas dépasser 1.5 kg et le robot doit être envoyé à une distance comprise entre 1.5 et 2 mètres maximum. Enfin, le robot devra être en “roue libre” lors de la phase de sortie du robot.

A. Première solution: Utilisation d’élastique


Icam, site de Toulouse | 75 avenue de Grande Bretagne | CS 97615 | 31300

22

Avantages | Inconvénients
-2 fonctions réalisées en une solution | -Grand effort exercé sur les arbres
-Optimisation de la place | -Grand effort exercé sur les élastiques (1.5kg maximum), risque de casser des élastiques
-Position des engrenages et du moteur modulable sur la hauteur | -Demande une bonne précision pour que les engrenages engrènent correctement
-Seulement 2 moteurs | -Forces appliquées sur les élastiques inégales, l’éjection ne sera pas droite
| -Demande une puissance élevée des moteurs
| -Tests réalisés non satisfaisants
Partie Treuil | Partie éjection

La mise en route d’un premier moteur, actionne l’enroulement du fil d’Ariane, et amène le mini robot à l'intérieur de la station hôte. Lors de son entrée dans la station, le mini robot va entrer en contact avec une plaque, reliée au châssis de la station par 2 élastiques placés aux extrémités de la plaque (représentés en rouge sur le schéma cinématique). En pénétrant un peu plus, le robot étant tiré vers l'intérieur de la station, va appliquer une force suffisante sur la plaque pour tendre les élastiques et les préparer à l’expulsion du mini robot. Puis, grâce au démarrage du second moteur, le système de roue libre va “libérer” le robot et les élastiques tendus vont propulser le robot vers l'extérieur de la station.


Icam, site de Toulouse | 75 avenue de Grande Bretagne | CS 97615 | 31300

23

B. Seconde solution: utilisation d’un ressort:
Avantages | Inconvénients
-2 fonctions réalisées en une solution | -Grand effort exercé sur les ressorts (1.5kg maximum)
-Optimisation de la place | -Demande une bonne précision pour que les engrenages engrènent correctement
-Plus facile à diriger et plus précis pour être aligné | -Demande une puissance élevée des moteurs

-Position des engrenages et du moteur modulable sur la hauteur

-Seulement 2 moteurs

La mise en route d’un premier moteur, actionne l’enroulement du fil d’Ariane, et amène le mini robot à l'intérieur de la station hôte. Lors de son entrée dans la station, le mini robot va entrer en contact avec une plaque, reliée au châssis de la station par 2 ressorts placés à l’arrière de la plaque (représentés en rouge et noir sur le schéma cinématique). En pénétrant un peu plus, le robot étant tiré vers l'intérieur de la station, va appliquer une force suffisante sur la plaque pour compresser les ressorts, et les préparer à l’expulsion du mini robot. Puis, grâce au démarrage du second moteur, le système de roue libre va “libérer” le robot, les ressorts, étant compressés, propulsent le robot vers l'extérieur de la station. Cette solution permettrait un lancer plus précis qu’avec l’utilisation d'élastiques.


Icam, site de Toulouse | 75 avenue de Grande Bretagne | CS 97615 | 31300

24

C. Troisième solution : (système treuil et éjection séparés)

Système d’éjection;

Système de treuil:

Avantages | Inconvénients
-Optimisation de la place | -4 moteurs (2 rotations et 2 translations)
-Système plus précis | -2 systèmes distincts
-Forces appliquées sur les ressorts égales | -Grand effort exercé sur les ressorts (1.5kg maximum)

Enrouleur

Ressort

Enrouleu


Icam, site de Toulouse | 75 avenue de Grande Bretagne | CS 97615 | 31300

25

La fonction treuil se définit par un enrouleur (en vert sur le schéma cinématique), relié au robot par un fil d’Ariane, qui va le ramener dans la station hôte.

Lorsque le robot va rentrer à l'intérieur de la station hôte, le robot va entrer en contact avec une plaque attachée à deux ressorts (en noir sur le schéma cinématique), celui-ci relié à un enrouleur en acier (et donc plus résistant) qui va comprimer les ressorts.

### C) Système de verrouillage

La partie verrouillage consiste à assurer la MAP du robot encastré dans le treuil. En effet, en faisant l’analogie avec la situation réelle, le robot pendant sa charge doit être fixe et sans mouvement parasite dans l’espace où il n’y a pas de pesanteur.
Nous avons imaginé de nombreuses solutions que nous présenterons avec des schémas mais nous détaillerons particulièrement la solution retenue après concertation avec les autres sous parties.
A. Première solution: système poulie/courroie avec 2 pinces et 2 engrenages

Ce système de verrouillage est composé d’un unique moteur encastré dans le treuil, au-dessus du robot. Ce moteur entraînera 2 engrenages liés avec 2 axes par courroie tournant en sens opposé. A ces 2 axes seront encastrées respectivement 2 pinces, qui, une fois en
contact avec le robot, le verrouillent.
En effet, elles suppriment le degré de liberté en translation.

Icam, site de Toulouse | 75 avenue de Grande Bretagne | CS 97615 | 31300

26

Avantages | Inconvénients
- nécessite qu’un seul moteur. - augmentation du couple moteur et de la puissance des pinces - tension de la courroie variable. - Optimisation de l’espace libre. - Suppression de tous les degrés de liberté. | - Contrainte d’espace. - La taille des pinces doit être élevée. - 4 encoches à usiner.

Avantages

- Les engrenages permettent de faire déplacer une pince dans un sens et l’autre dans le sens inverse ainsi un seul moteur suffit à faire bouger les 2 pinces.
- Le couple moteur et la puissance des pinces sont augmentés grâce aux engrenages.
- La tension de la courroie peut être choisie en fonction du besoin d’écartement des pinces.
- Ce système est rattaché au plafond de la station hôte. Le système se situe donc au-dessus du mini-robot, on utilise donc l’espace libre. Cela permet de ne pas gêner les autres parties notamment celle pour l'expulsion du robot.
- Les pinces vont venir se fixer sur le châssis du mini-robot dans lequel se trouvent des encoches donc il n’y aura plus aucun degré de liberté.

Inconvénients

- La hauteur du système ne doit pas dépasser 10 cm, le système prend trop de place.
- Les pinces ne doivent pas être trop petites sinon la force appliquée sur le mini robot ne sera pas assez grande pour fixer totalement le robot.
- Le robot doit être usiné de façon à posséder 4 encoches au total pour accueillir les pinces.
B. Seconde solution : système avec plusieurs engrenages et 2 pinces

Similaire à la solution 1, un seul moteur dirige 2 axes de sens de rotation opposés composés de 2 pinces maintenant en position le robot. Cependant, à la place d’une courroie, des engrenages assurent la fonction de transmission de rotation aux axes parallèles. Ce système prend donc plus d’espace via la présence de nombreux engrenages.


Icam, site de Toulouse | 75 avenue de Grande Bretagne | CS 97615 | 31300

27

Avantages | Inconvénients
- Mêmes avantages qu'à la première solution | - Système trop incertain et complexe. - Manque d’espace

Inconvénients

- Il y a trop d’engrenages donc le système est trop incertain et complexe. En effet, plus il y a d’engrenages, plus les 2 axes sont susceptibles de ne pas tourner à la même vitesse.
- Il manque d’espace en hauteur. En effet, il est trop difficile de créer un système avec 4 engrenages et 2 pinces qui mesure 10 cm en hauteur.
C. Troisième solution : système de glissière avec cales relié à la charge

Nous avons eu l’idée de relier le verrouillage au docking. Pour la charge, ils utilisent un système d’électrodes qui vient se fixer au mini-robot grâce à un système de glissière (par l’intermédiaire d’une liaison pignon-crémaillère). Sur la branche avec les électrodes, nous aurions fixé 2 cales (2 surfaces perpendiculaires) de part et d'autre du côté gauche du robot.
Ainsi cette solution permettrait d’allier charge et verrouillage du robot afin de ne pas multiplier les sous-systèmes autour du robot et pouvant sensiblement rendre complexe son fonctionnement. En effet un seul moteur commanderait cette action.
Vue de coté | Vue de dessous

Icam, site de Toulouse | 75 avenue de Grande Bretagne | CS 97615 | 31300

28

Avantages | Inconvénients
-La charge et le verrouillage se font simultanément. -Le treuil serait moins chargé en composants et en moteurs. | -Tout doit être mis en place pour que le système de verrouillage puisse charger. -Fragilité des électrodes -Conception technique pour allier les 2 fonctions.

Inconvénients

- Les électrodes ne doivent pas s'abîmer au contact du système de verrouillage qui applique une force de pression importante sur le robot.
D. Quatrième solution: Système de cales pivotantes

Deux cales de forme triangulaire vont venir pivoter pour s’encastrer dans le mini-robot. Quand le robot rentre dans le treuil, les cales sont entraînées par un moteur, rentrant en contact avec le robot et assurant son maintien en position. Un usinage dans le robot permettra aux cales sous tension de s'encastrer dans le robot. Avant la propulsion du robot, le pivotement des cales se fera à l’aide d’un système comprenant un moteur relié à un arbre sur lequel se trouve un engrenage. Cet engrenage emmènera un autre engrenage en rotation. Chaque engrenage sera relié à un système de poulie courroie qui sera lui-même relié aux cales afin de les faire pivoter.

Vue de face | Vue de dessus

Icam, site de Toulouse | 75 avenue de Grande Bretagne | CS 97615 | 31300

29

Avantages | Inconvénients
- Nécessite qu'un seul moteur. - Optimisation de l’espace. - Suppression de tous les degrés de liberté. - Solution simple et peu encombrante. | - La hauteur du système ne doit pas dépasser 10 cm - Les cales ne doivent pas gêner le système de docking

Avantages

- Les engrenages permettent de faire pivoter une cale dans un sens et l’autre dans le sens inverse ainsi un seul moteur suffit à faire pivoter les deux cales
- Ce système est rattaché au plafond de la station hôte. Le système se situe donc au-dessus du mini-robot, on utilise donc l’espace libre. Cela permet de ne pas gêner les autres parties notamment celle pour l'expulsion du robot.
- Les cales vont venir s’emboiter sur le châssis du mini robot dans lequel se trouve des encoches donc il n’y aura plus aucun degré de liberté.
- L’utilisation de cales est une solution bien plus simple et moins encombrante que l’utilisation de pinces.
E. Solution 5: (solution finale) système de cales avec ressort

Deux cales triangulaires de part et d’autre de la station hôte vont pivoter grâce à deux ressorts pour venir s’encastrer dans le mini robot. Chaque cale va être en contact avec un ressort encastré sur une surface rectangulaire. Lorsque le mini-robot entre dans la station hôte, il s'appuie sur les cales et les deux ressorts se compriment. Une fois le robot entré, les ressorts vont se détendre et les deux cales vont venir s’encastrer dans les encoches du châssis du mini-robot prévu à cet effet.


Icam, site de Toulouse | 75 avenue de Grande Bretagne | CS 97615 | 31300

30

Avantages | Inconvénients
- Système simplifié. - Moteur utile que pour le verrouillage. - Système peu encombrant. | -Besoin de deux moteurs. - Les moteurs doivent tourner simultanément. -Prend de la place

Avantages

- Le système est simplifié, il n’y a pas d’ engrenage et de poulie courroie.
- Seuls les ressorts seront nécessaires au verrouillage (pas besoin d’utiliser de moteur). Les moteurs seront seulement nécessaires pour le déverrouillage du mini robot.

Inconvénients
- Il est nécessaire d’utiliser deux moteurs de part et d’autre du mini robot.
- Ce système prend de la place sur les côtés du robot.

Schéma cinématique de la solution finale de verrouillage

### d) Docking

La partie docking du robot s’occupe de l’alimentation du mini-robot. La station hôte sera alimentée grâce à un câble électrique branché à une prise de 220V et transformé en 12V.

Dans cette partie, nous avons cherché à dimensionner la batterie et à étudier les différentes possibilités de chargement.

Icam, site de Toulouse | 75 avenue de Grande Bretagne | CS 97615 | 31300

31

A. Première solution : Chargement par induction

Le chargement par induction est une méthode de transfert d'énergie électrique entre deux dispositifs sans qu'ils soient physiquement connectés. Cela fonctionne en faisant circuler un courant électrique à travers une bobine de cuivre émettrice connectée à une source d’alimentation électrique. Ce système crée un champ magnétique faisant apparaître un second courant électrique au niveau d’une autre bobine qui se trouve sur le mini-robot.

Le courant induit dans la bobine réceptrice est ensuite
converti en énergie électrique utilisable pour alimenter
la batterie du mini-robot. Cette solution aurait pu être une bonne option mais pour assurer un transfert d'énergie optimal, il est important que la bobine émettrice et la bobine réceptrice soient alignées correctement. Or dans notre cas et à ce stade de l’avancement du projet, on ne peut pas placer précisément des bobines et mettre en place tout le mécanisme de chargement de manière simple.
Avantages | Inconvénients
- Par champ électromagnétique - Esthétique | - Manque de précision pour l’alignement des bobines - Les bobines de cuivre prennent trop de place - Compliqué de gérer l’enclenchement de la charge - Temps de chargement assez important
B. Seconde solution: charge par MIR

La MIR (Mobile Industrials Robots) est une station de charge autonome. Elle est notamment utilisée dans les aspirateurs sans fil.

Le mini-robot retourne de manière intelligente à la station hôte, se connecte et se met en charge. Le mécanisme de cette solution pourrait alors être envisagé. Cependant, cette solution est bien trop complexe à réaliser et n’aurait aucun intérêt à être directement achetée.

Icam, site de Toulouse | 75 avenue de Grande Bretagne | CS 97615 | 31300

32

Avantages | Inconvénients
- Charge rapide - Possibilité de définir un seuil pour renvoyer à la charge - Seulement alimenté par une prise 220 V | - Prix important - Trop lourd - Trop grand - Trop performant par rapport à notre projet
C. Troisième solution: charge par électrodes

La troisième solution est d’utiliser un chargement par électrode. Ce système est notamment utilisé pour des appareils domestiques autonomes tels que les robots aspirateurs et les tondeuses.

Ce type de robot est équipé de batteries rechargeables (généralement en lithium-ion) qui alimentent un moteur électrique.

Il possède une station hôte connectée à une source d’alimentation électrique et équipée d’une base conductrice. Lorsque la batterie atteint un niveau bas ou que le robot a accompli sa tâche, le robot utilise ses capteurs pour retourner à la station de charge.

Lorsque le robot est retourné à sa station, il descend automatiquement ses contacts électriques sur la base de recharge. Ces contacts établissent une connexion électrique entre la station de charge et la batterie du robot.

Une fois la connexion établie, le courant électrique de la source d'alimentation de la station de charge est utilisé pour recharger la batterie du robot.

Ainsi ce mécanisme semblerait être une bonne solution de fonctionnement de recharge pour notre projet.

Avantages | Inconvénients
- Ne prends pas beaucoup de place sur la station hôte ou même sur le mini-robot - La charge peut s’enclencher en même temps que le verrouillage | - Besoin d’un transformateur entre le câble d'alimentation et la batterie - Besoin d’isoler le robot étant donné que le bâtis serait fait en aluminium


Icam, site de Toulouse | 75 avenue de Grande Bretagne | CS 97615 | 31300

33

❖ Choix de la batterie

Pour réaliser cette solution, il est nécessaire de choisir quelle est la batterie que nous allons utiliser. Il y a deux possibilités :

- Batterie en lithium
Avantages | Inconvénients
- Pas très lourd - Prix abordable - La plupart des robots fonctionnent avec donc c’est une solution fonctionnelle | -Peut être trop puissante, performante pour les attentes de notre robot - Être sur du dimensionnement de la batterie
- Batterie en nickel
Avantages | Inconvénients
- Durée de vie élevée - Capacité élevé | - Poids élevé - Coût élevé - Moins d'efficacité que certaines alternatives ( que celle au lithium par exemple )

❖ Choix des électrodes:

C’est le cuivre qui semble être le matériau le plus adapté. En effet, c’est un matériau très conducteur, il résiste à la corrosion et possède un bon rapport économique.


Icam, site de Toulouse | 75 avenue de Grande Bretagne | CS 97615 | 31300

34

# VI) Commande

A. Choix Moteurs

Notre travail est axé sur la recherche de composants électroniques (moteurs, drivers, ...) pour pouvoir répondre aux besoins énergétiques de chaque sous-partie du projet. Nos premières séances de travail ont consisté à répertorier tous les moteurs susceptibles d’être utilisés pour la suite du projet en fonction de leur type de fonctionnement, de leurs besoins électriques et de leurs autres caractéristiques techniques (cf annexe).
Nous avons déjà pu formuler des pistes de recherches aux solutions techniques notamment trouver le type (moteur pas à pas, motoréducteur,...) de chaque moteur présent sur les solutions des sous-systèmes.

Diagramme représentant les besoins de chaque sous-partie avec un pré-choix du type de moteur.

B. Choix Drivers

Pour pouvoir contrôler de manière efficace et précise un moteur sur Arduino, on doit choisir judicieusement les dispositifs électroniques nécessaires comme des drivers ou des bridges (petites puces électroniques). En fonction du type de moteur que nous utilisons, on prévoit un modèle de contrôle compatible avec un code arduino.

Tableau des contrôleurs répertoriés, en fonction de leur compatibilité avec les moteurs

Icam, site de Toulouse | 75 avenue de Grande Bretagne | CS 97615 | 31300

35

Nous avons déjà pu effectuer quelques simulations pour le contrôle des moteurs pas à pas. Pour produire un code fonctionnel avec les modèles de moteurs pas à pas (cf annexe) notamment avec un driver de notre liste : le A4988. Mais aussi pour les servomoteurs qui sont directement équipés d’un encodeur.

C. Choix Carte Arduino

Nous nous occupons aussi de l’implémentation électronique de la totalité du système station hôte et mini-robot. Avec les parties châssis du mini-robot et de la station hôte nous nous mettons d’accord sur l’emplacement de la carte mère (sur ce projet on utilisera des cartes Arduino) en fonction de leur dimensionnement, ainsi que du reste du matériel électronique (breadboard, encodeur, drivers, ...)

Choix des cartes arduino avec leur dimensionnement et leur consommation électrique. Les 3 cartes arduinos délivrent une tension égale à 3.3V ou 5V.

D. Choix batterie

Nous nous sommes également intéressés au choix de la batterie pour alimenter le mini-robot. Pour cela, nous avons calculé la consommation des moteurs présents, qui sont aux nombres de 4 et qui ont chacun une intensité d’environ 1,5 ampère (estimation utilisée principalement pour le calcul). Il faut également rajouter la consommation de la carte arduino ainsi que des drivers. De plus, nous savons que nous voulons faire fonctionner le mini-robot pendant au moins 5 minutes (nous prendrons 10 minutes pour le calcul afin d’avoir de la marge). Tout cela nous permet de trouver une batterie d’au moins 1050 mAh.

Tableau des batteries, avec des capacités au moins 2 fois supérieur à 1050mAh pour avoir une marge confortable.

E. Répartition des tâches

La partie recherche des composants électroniques a été réalisée à deux, en nous répartissant la recherche et la documentation des moteurs. Chacun s’est vu attribuer les sous-systèmes du robot afin d’en connaître les besoins et de proposer les moteurs les plus adaptés. A la fin de chaque séance, nous nous tenions informés de nos avancées et des besoins de chacune des parties.

Icam, site de Toulouse | 75 avenue de Grande Bretagne | CS 97615 | 31300

36

Nous travaillons également en collaboration avec le pôle transmission et pilotage de la caméra. Par la suite, leur solution nous sera soumise afin qu’on puisse choisir le moteur adéquat et qu’on l’intègre dans le reste du système mini-robot.

# V) Schémas cinématiques

### Mini robot:


Icam, site de Toulouse | 75 avenue de Grande Bretagne | CS 97615 | 31300

37

### Station hôte

Icam, site de Toulouse | 75 avenue de Grande Bretagne | CS 97615 | 31300

38

# VI) Gestion du reporting

Ci-dessous, nous avons énuméré les éléments de travail de chaque sous-partie pour les prochaines semaines jusqu’au jalon 2 à rendre pour le 4 mars 2024.

Les objectifs principaux sont la réalisation du Solidworks du robot et de sa station hôte ainsi que les différents pré-dimensionnements nécessaires (RDM, hyperstatisme,...).

| Semaine 09 | Semaine 10
Châssis Mini Robot | -Modélisation du mini robot sur Solidworks. | -Définition des éléments constitutifs de chaque liaison cinématique.
Déploiement Caméra | -Dimensionnement des moteurs. -Dimensionnement des engrenages. | -Choix des éléments, usinage.
Transmission Pilotage | -Test de la solution Camera - Création de la manette | -Mise en place du codage.
Châssis Station Hôte | -Modélisation du châssis sur Solidworks, Solidworks de la station hôte | -Définition des éléments constitutifs de chaque liaison cinématique.
Système d'éjection et système de Treuil | -Dimensionnement du ressort, fil (raideur, longeur). Calcul théorique. | -Choix du ressort, fil et enrouleur, passer commande.
Système de verrouillage | -Dimensionnement des moteurs. -Dimensionnement des engrenages. | -Modelisation solidworks. -Définition des éléments constitutifs de chaque liaison cinématique.
Docking | -Solution de mise en place de la connectique et du système de recharge. | -Choix de la connectique.
Commande | -Dimensionnement de la batterie. -Mise en place du codage par partie. | -Test moteur.


Icam, site de Toulouse | 75 avenue de Grande Bretagne | CS 97615 | 31300

39

# VII) Annexes:

a) Partie pilotage de la caméra

Code pilotage

b) Partie commande

Tableau des moteurs répertoriés, nos deux fournisseurs principaux sont français : Lextronics et GoTronic


Icam, site de Toulouse | 75 avenue de Grande Bretagne | CS 97615 | 31300

40

Simulation moteur pas à pas :

Exemple de schéma de fonctionnement d’un moteur pas-à-pas avec son driver A4988

Simulation servomoteur :

Exemple de schéma de fonctionnement d’un servomoteur

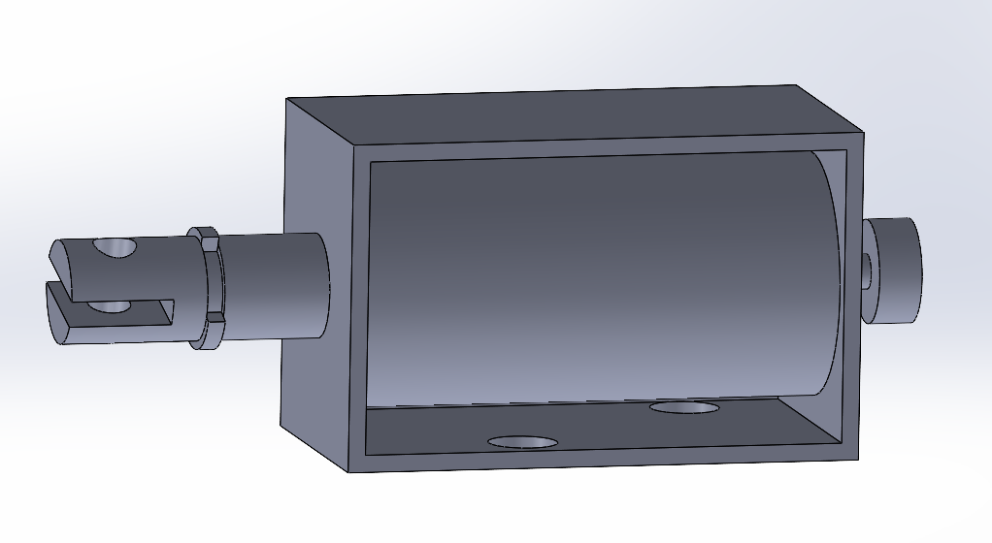
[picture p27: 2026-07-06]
Station Hote/Docking/Final/captures finales/solenoide.PNG

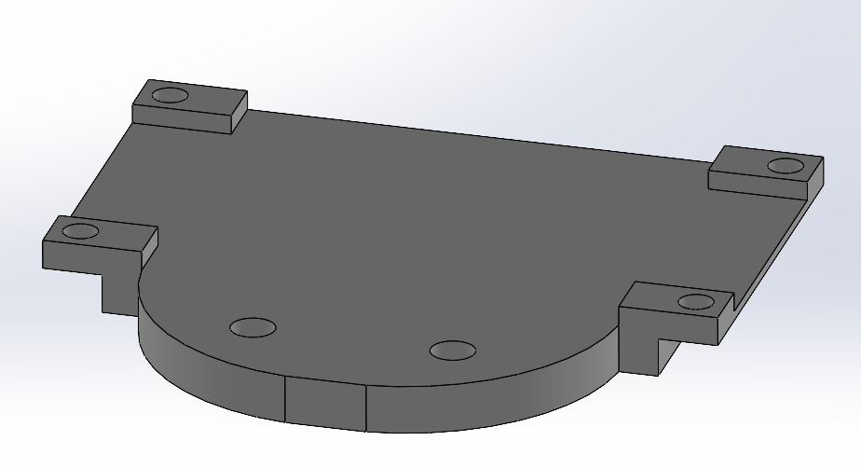
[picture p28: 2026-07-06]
Station Hote/Docking/Final/captures finales/support_convertisseur_cc_cv.PNG

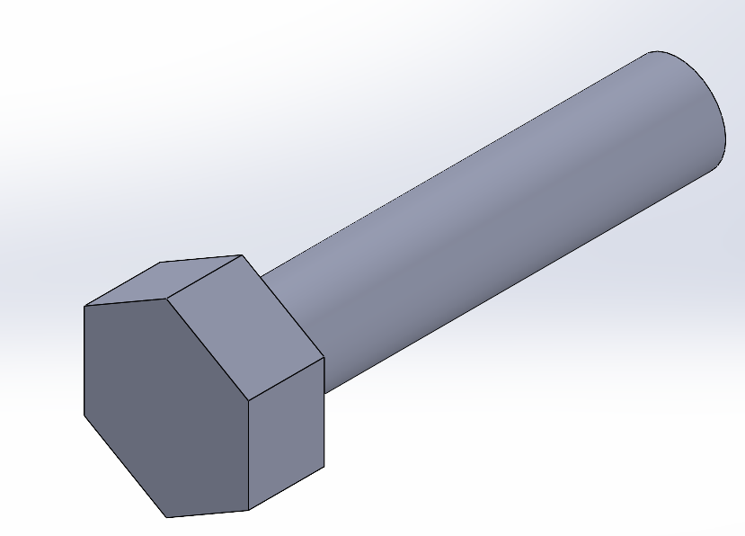
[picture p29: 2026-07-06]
Station Hote/Docking/Final/captures finales/vis_M2.5-9.PNG

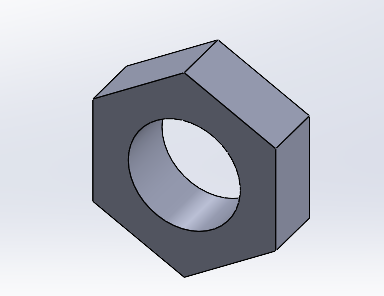
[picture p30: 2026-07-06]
Station Hote/Docking/Final/captures finales/ecrou_M3.5.PNG

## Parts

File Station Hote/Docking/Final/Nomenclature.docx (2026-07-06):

NOMENCLATURE

Partie Docking

Hemar Noemie

Rodriguez Lucas

Assemblage 1 :

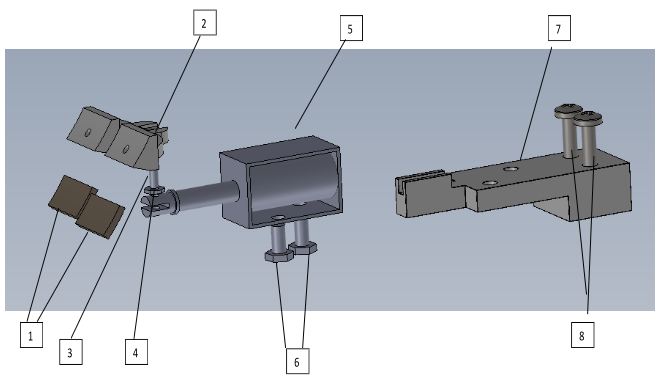
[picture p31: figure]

1. électrode en nickel | 3. vis M2.5-9 | 5. moteur solénoïde | 7. support+guidage pour le moteur solénoïde
2. support pour les électrodes | 4. écrou M2.5 | 6. vis M4-8 | 8. vis M4 de la station hôte

Assemblage 2 :

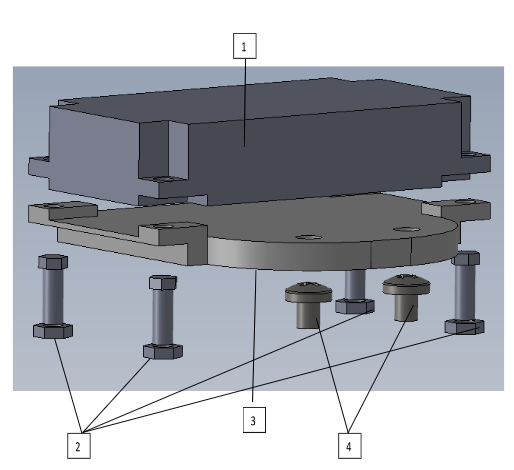
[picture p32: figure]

1. convertisseur cc/cv | 3. support convertisseur cc/cv
2. ensemble vis M3.5-10/écrou M3.5 | 4. vis M4-5

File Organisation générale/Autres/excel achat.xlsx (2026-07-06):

Ref de la piece | Lien de la commande | Prix | Quantité | Sous-sytèmes sollicités | liens utiles :
OV2640 | https://www.amazon.fr/SHMIZZ-OV2640-degr%C3%A9s-Module-ESP32-CAM/dp/B0C2HKXV8K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 | 15.60€ | 1 | Transmission/pilotage (caméra) |  | Profilé : MOTEDIS
 |  |  |  |  |  | Roulement : 123Roulement
 |  |  |  |  |  | Vis, écrou, rondelle, goupille : BRICOVIS ou CERGY VIS
 |  |  |  |  |  | Coussinet : IGUS
 |  |  |  |  |  | Divers Composants : CASTO ou LEROY MERLIN
 |  |  |  |  |  | Electronique : LEXTRONIC ou GOTRONIC ou RS.ONLINE
Batterie lithium Ion 3S 3500mah avec BMS | Batterie lithium Ion 3S 3500mah avec BMS (robot-maker.com) (https://www.robot-maker.com/shop/alimentation/434-batterie-lithium-ion-3s-3500mah-avec-bms-434.html) | 30.00€ | 1
 |  |  |  | provisoire
ressort (T030-180-172L) | https://www.ressorts-sodemann.fr/t030-180-172l | 5.48 | 1 | verrouillage

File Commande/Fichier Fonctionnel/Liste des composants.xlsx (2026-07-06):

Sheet: LISTE MOTEUR
 | MODELE | ALIMENTATION | INTENSITÉ (en A) | PUISSANCE | COUPLE | TOUR PAR MIN | NOMBRE DE PAS | POIDS (en g) | DIMMENSION (en mm) | PRIX (TTC) | LIEN
Moteur pas à pas | NEMA17-06 (icam) | 3,6V | 2 | 7,2W | 0,59Nm | jusqu'à 300tr/min | 200 pas (1,8°) | 420 | 42x42x48 | 28.90€ | https://www.lextronic.fr/moteur-pas-a-pas-de-precision-nema17-64265.html
 | NEMA8-01 | 3,9V | 0.6 | 2,34W | 0,018Nm | - | 200 pas (1,8°) | 60 | 20x22x50 (arbre) | 23.99€ | https://www.lextronic.fr/mini-moteur-pas-a-pas-nema8-01-64823.html
 | NEMA8-02 | 4V | 0.8 | 3,2W | 0,020Nm | - | 200 pas (1,8°) | 80 | 20x22x61,7 (arbre) | 24.99€ | https://www.lextronic.fr/mini-moteur-pas-a-pas-nema8-02-64824.html
 | NEMA8-03 | 4,26V | 0.6 | 2,56W | 0,022Nm | - | 200 pas (1,8°) | 60 | 20x22x37,3 (arbre) | 23.99€ | https://www.lextronic.fr/mini-moteur-pas-a-pas-nema8-03-64837.html
 | NEMA8-05 (arbre creux) | 3,9V | 0.6 | 2,34W | 0,018Nm | - | 200 pas (1,8°) | 60 | 20x22x37 (arbre) | 29.99€ | https://www.lextronic.fr/moteur-pas-a-pas-nema8-05hs-a-arbre-creux-64831.html
 | NEMA17-02 (arbre traversant) | 2,8V | 1.68 | 4,70W | 0,431Nm | - | 200 pas (1,8°) | 400 | 42,3x42,3x47 (arbre) | 32.90€ | https://www.lextronic.fr/moteur-pas-a-pas-nema17-arbre-traversant-39848.html
 | NEMA11-02 | 6,5V | 0.67 | 4,36W | 0,008Nm | jusqu'à 3000 tr/min | 200 pas (1,8°) | 200 | 28,2x28,2x71,7 (arbre) | 24.99€ | https://www.lextronic.fr/moteur-pas-a-pas-nema11-02-64829.html
 | NEMA11-01 | 5V | 0.42 | 2,1W | 0,055Nm | - | 200 pas (1,8°) | 120 | 28,2x28,2x52 (arbre) | 20.49€ | https://www.lextronic.fr/moteur-pas-a-pas-nema11-01-64835.html
 | NEMA17-01 | 2,8V | 1.86 | 5,21W | 0,043Nm | jusqu'à 300tr/min | 200 pas (1,8°) | 365 | 42,3x42,3x47 (arbre) | 30.00€ | https://www.lextronic.fr/moteur-pas-a-pas-de-precision-nema17-76781.html
 | NEMA17-03 | 5V | 1.2 | 6W | 0,2 Nm | - | 200 pas (1,8°) | 150 | 42x42x27 | 13.50€ | https://www.lextronic.fr/moteur-pas-a-pas-nema17-03-64826.html
 | NEMA23-05 | 6,5V | 1 | 6,5W | 1,32Nm | - | 200 pas (1,8°) | 1000 | 56x56x96 (arbre) | 34.99€ | https://www.lextronic.fr/moteur-pas-a-pas-nema23-05-64825.html
 | NEMA14-02 | 4,35V | 0.75 | 3,26W | 0,15Nm | - | 200 pas (1,8°) | 180 | 35,3x35,3x54 (arbre) | 22.90€ | https://www.lextronic.fr/moteur-pas-a-pas-nema14-02-64834.html
Solénoïde | Electro-aimant Push 12 V | 12V | 0.5 | 6W | 3,8mm de course | force : 150g | - | 15 | 37,3/33x12x11 | 10.20€ | https://www.lextronic.fr/solenoide-push-12-v-150-g-58747.html
 | Electro-aimant Push Pull 12 V | 12V | 0.6 | 7,2W | 8 mm de course | force : 40g | - | 45 | 50x16x19 | 11.40€ | https://www.lextronic.fr/solenoide-push-pull-12-v-course-8-mm-58749.html
 | électro-aimant Push 12 V grande course | 12V | 0.63 | 7,5W | 21 mm de course | force : 50g | - | 215 | 87,4 x 31 x 25,4 | 19.19€ | https://www.lextronic.fr/solenoide-push-12-v-grande-course-58751.html
Motoréducteur | Motoréducteur 37025GM-12280 | 12V/6V | 1.2 | 14,4W | 0,069Nm | 230 tr/min | réduction:23,1:1 |  | 25x65,3x25 | 16.20€ | https://www.lextronic.fr/motoreducteur-37025gm-12280-76344.html
 | Motoréducteur 52037GM-12320 | 12V/6V | 1.5 | 18W | 0,066Nm | 224 tr/min | 18,8:1 |  | 37x69,7x37 | 20.40€ | https://www.lextronic.fr/motoreducteur-52037gm-12320-76430.html
 | Motoréducteur avec encodeur E20GM-1200500 | 12V/6V | 2.5 | 30W | 0,042Nm | 396 tr/min | 25:1 |  | 20x58,5x20 | 19.21€ | https://www.lextronic.fr/motoreducteur-avec-encodeur-e20gm-1200500-76773.html
 | Motoréducteur 4745 (Pololu DC37) | 12V/6V | 5.5 | 66W | 3,4Nm | 100 tr/min | 100:1 | 195 | 37x57x37 | 40.80€ | https://www.lextronic.fr/motoreducteur-4745-pololu-dc37-64403.html
Servomoteurs | Feetech FS5106B | 4,8V/6V | 0.9 | 5,3W | 0,58/0,49Nm | 64,8 tr/min | rotation : 120° | 40 | 40,8x20,1x38 | 10.40€ | https://www.gotronic.fr/art-servomoteur-analogique-fs5106b-25829.htm
 | Feetech FS5109M | 4,8V/6V | 1.6 | 9,6W | 0,88/1Nm | 64,8tr/min | rotation : 180° | 56 | 40,8x20,1x38 | 16.50€ | https://www.gotronic.fr/art-servomoteur-fs5109m-25830.htm
 | Feetch FS5115M | 4,8V/6V | 1.2 | 7,2 W | 1,52/1,37Nm | 64,8tr/min | rotation : 180° | 56 | 40,8x20,1x38 | 19.50€ | https://www.gotronic.fr/art-servomoteur-fs5115m-25831.htm
 | FS5103B (icam) | 4,8V/6V | 0.18 | 1,8W | 0,3/0,32Nm | 64,8tr/min | rotation : 180° | 36 | 41x20x38 | 8.85€ | https://www.gotronic.fr/art-servomoteur-fs5103b-25828.htm
 | SG90 | 4,8V |  |  | 0,16Nm | 100tr/min | rotation : 180° | 9 | 23x12.2x29 | 3.60€
à rotation continue | Feetech à rotation continue FS5103R | 4,8V/6V | 0.7 | 4,08W | 0,3/0,32Nm | 64,8tr/min | rotation: 360° | 36 | 40,8 x 20,1 x 38 | 10.50€ | https://www.gotronic.fr/art-servomoteur-fs5103r-25839.htm

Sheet: CHOIX POUR LES ACHATS
Quantité | Moteur | Baterie | Prix total : | 28.9 | Capacité Baterie (en mAh) | Durée de vie baterie (en min)
1 | NEMA17-06 (icam) |  | Poids : | 420 | 2500 | 6.818181818
0 | NEMA8-01 |  | Ampére total : | 2
0 | NEMA8-02
0 | NEMA8-03 |  |  | 22
0 | NEMA8-05 (arbre creux)
0 | NEMA17-02 (arbre traversant)
0 | NEMA11-02
0 | NEMA11-01
0 | NEMA17-01
0 | NEMA17-03

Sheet: Liste Drivers
Modèle | Type de composant | Compatibe avec les moteurs | Prix | Lien
DRV8434A 3764 | Driver de moteur | pas-à-pas | 15.25€ | https://www.gotronic.fr/art-driver-de-moteur-pas-a-pas-drv8434a-3764-35989.htm
ULN2004A | Réseau de transistors | pas-à-pas | 0.70€ | Réseau de 7 transistors - ULN2004A (https://www.gotronic.fr/art-uln2004a-10726.htm)
ULN2804A | Réseau de transistors | pas-à-pas | 2.50€ | https://www.gotronic.fr/art-uln2804a-10728.htm#complte_desc
A4988 2128 | Driver de moteur | pas-à-pas | 16.50€ | https://www.gotronic.fr/art-driver-de-moteur-pas-a-pas-a4988-2128-21717.htm
H L298N (à l'icam) | Double commande | motoréducteur et moteur à CC | 5.90€ | https://www.gotronic.fr/art-commande-de-2-moteurs-sbc-motodriver2-27418.htm
Shield moteur GT1138 | Shield | motoréducteur, pas à pas, servomoteurs | 8.90€ | https://www.gotronic.fr/art-shield-moteur-4-x-0-6-a-gt1138-26141.htm
L293D | Puce électronique | motoréducteur et moteur à CC | 6.90€ | https://www.gotronic.fr/art-l293d-14072.htm

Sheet: Feuille 4
Composants électroniques | Nombre | Tension (V) | Intensité (A) | Puissance (W)
STATION HÔTE
Polulu DC37 4744 | 1 | 12/6V | 5,5/3A | 65/18W
WT341 | 2 | 6V | 2A | 12W
Lex-Solen 04 | 1 | 12V | 0,6A | 7,2W
17HS08-1004S | 1 | 12V | 1A | 12W
A4988 | 1 | 5,5V | ≈ | ≈
CC H L298N | 2 | 5V | ≈ | ≈ | Tension à délivrer : 12/5V
RX433 | 1 | 5V | 2mA | 10mW | Intensité total : 8,5A
MINI ROBOT
Servomoteur SG90 | 1 | 5V | 0,19A | 0,95W
SY35ST28-0504A | 1 | 10V | 0,5A | 5W
A4988 | 1 | 5,5V | ≈ | ≈ | Tension à délivrer : 10/5V
RX433 | 1 | 5V | 2mA | 10mW | Intensité total : 0,69A

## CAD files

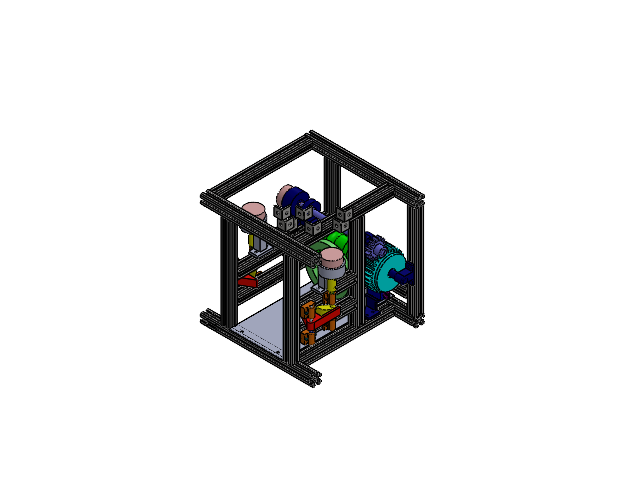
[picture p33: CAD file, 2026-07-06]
Station Hote/SolidWorks/Station hote/Final.SLDASM
Profilé final 210 mmm x 12
Support axe ressort x 4
Axe de Rotation Cale a ressort x 2
Cale a ressort finale x 2
Support axe moteur x 4
Roulement 8 5 2,5 x 4
Axe de Rotation cale moteur x 2
Vis 14 mm x 8
RESSORT x 2
Cale moteur finale x 2
Vis 10 mm x 8
Support moteur vérouillage x 2
moteur x 3
Raccord Moteur Axe Verrouillage x 2
Profile verouillage x 2
Profile 20 mm x 2
Profile 15 mm x 2
Profile 5 mm x 2
axe solenoide x 2
Cage moteur solénoide x 2
support_ressort
Pièce2^Assemblage_final
cylindre interieur x 2
bon_capuchon
ELECTRODE x 2
ISOLANT x 2
Support solenoide docking
Taule mini robot
arbre william
roulement d=10 x 4
bague d'arret william x 2
pan head cross x 2
FIxation arbre 1
Support moteur treuil
arbre 2
bobine avec pied
coffre cote disque ferrodo x 2
coffre bobine
Roulement à bille linéaire
bague d_arret william x 2
Cale solenoide
Support Arbre treuil
Support solenoide treuil
Roue Mobile 2.5M 29T
Pignon Treuil V2
anneau lancement robot
RESSORT V1 x 2
Profilé final 165.5 mmm
Profilé final 250 mm x 2
Equerre Final x 8

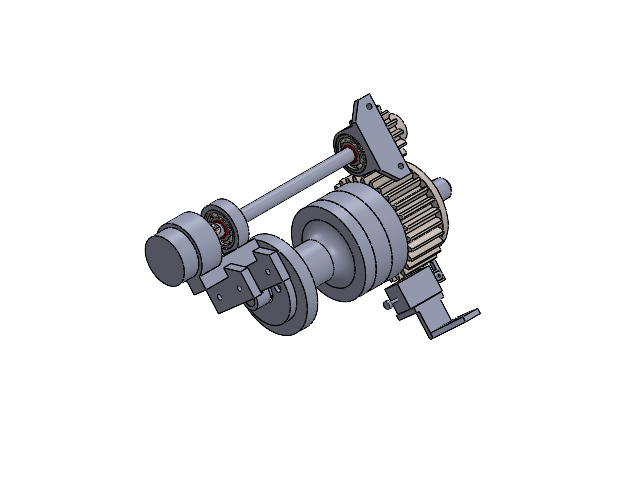
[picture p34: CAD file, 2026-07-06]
Station Hote/SolidWorks/Treuil/Assemblage Finale.SLDASM
Roue Mobile 2.5M 29T
arbre william
roulement d=10 x 4
bague d'arret william x 2
pan head cross recess screw_iso x 2
FIxation arbre 1
Support moteur treuil
arbre 2
bobine avec pied
coffre cote disque ferrodo x 2
coffre bobine
Roulement à bille linéaire
moteur
Cage moteur solénoide
cylindre interieur
axe solenoide
bague d_arret william x 2
Cale solenoide
Pignon treuil V1
Support Arbre treuil
Support solenoide treuil

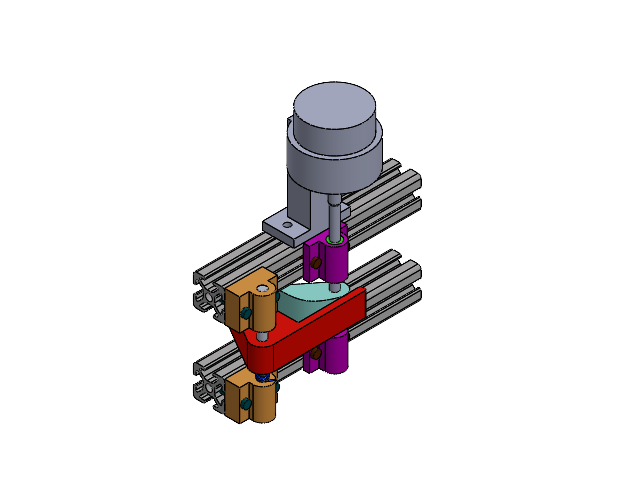
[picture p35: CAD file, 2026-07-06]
Station Hote/SolidWorks/Verrouillage/ASSEMBLAGE VERROUILLAGE 2.SLDASM
Support axe ressort x 2
Axe de Rotation Cale a ressort
Cale a ressort finale
Support axe moteur x 2
Roulement 8 5 2,5 x 2
Axe de Rotation cale moteur
Vis 14 mm x 4
RESSORT
Cale moteur finale
Vis 10 mm x 4
Profile verouillage x 2
Support moteur vérouillage
moteur

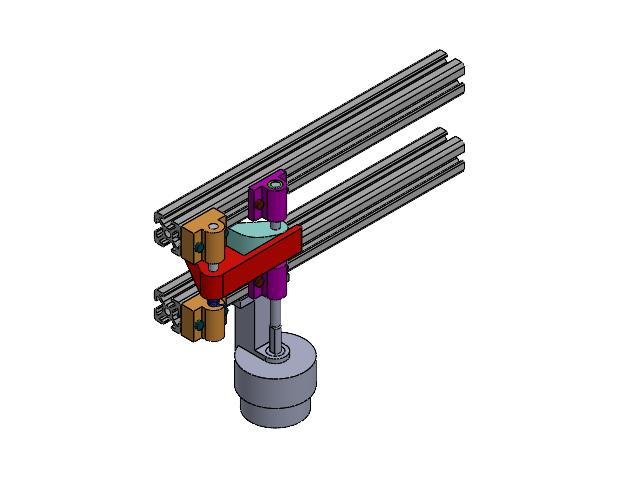
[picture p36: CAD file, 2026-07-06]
Station Hote/SolidWorks/Verrouillage/ASSEMBLAGE VERROUILLAGE 1.SLDASM
Support axe ressort x 2
Axe de Rotation Cale a ressort
Cale a ressort finale
Support axe moteur x 2
Roulement 8 5 2,5 x 2
Axe de Rotation cale moteur
Vis 14 mm x 4
RESSORT
Cale moteur finale
Vis 10 mm x 4
Profilé final 210 mmm x 2
Support moteur vérouillage
moteur

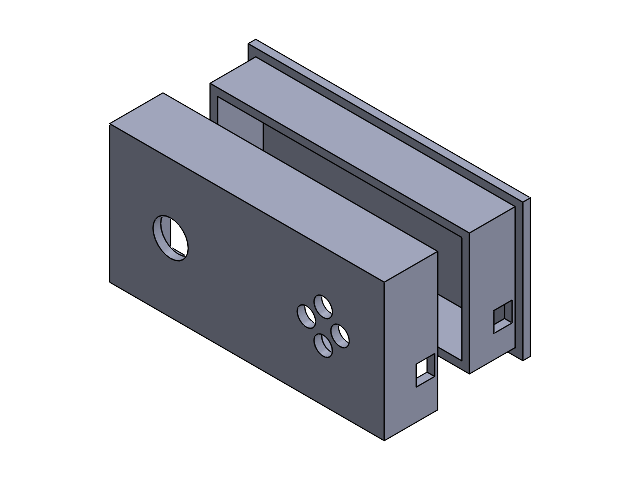
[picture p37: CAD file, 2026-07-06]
Station Hote/SolidWorks/Manette/Manette.SLDASM
Bas manette
Haut manette

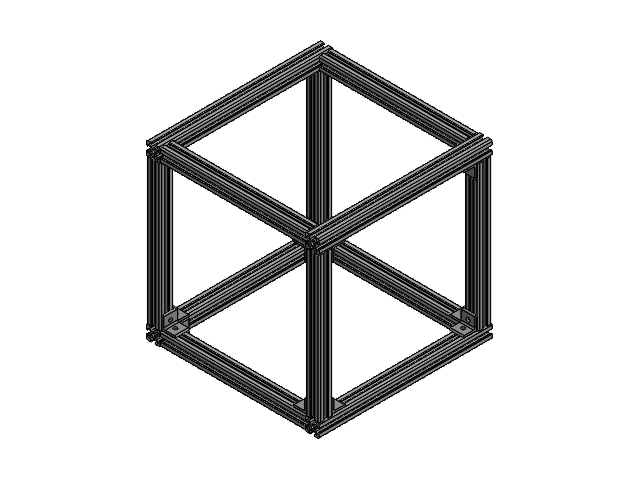
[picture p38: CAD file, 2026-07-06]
Station Hote/SolidWorks/Station hote/chassis/Châssis avec bon profilés OK.SLDASM
Profilé final 250 mm x 4
Profilé final 210 mmm x 8
Equerre Final x 14

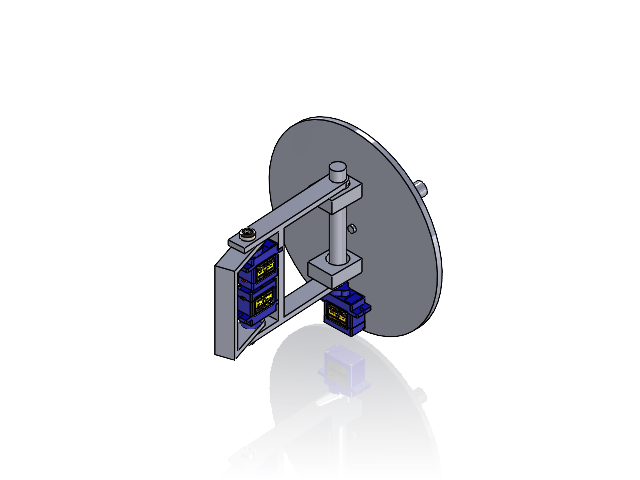
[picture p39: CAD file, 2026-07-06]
Mini robot/Système caméra/Schéma et Solidworks/solidwork bras/Assemblage.SLDASM
socle 1 x 2
cylindre racordement deux socles
bras 1 partie du dessous
bras 2 partie du dessus
Cercle
spur gear_iso x 2
Servo Motor MG996R
Servo Motor MG996R Hélice
socle pignon
hexalobular socket pan head_iso x 2
SG90 - Micro Servo 9g - Tower Pro.1 x 3
SG90 - Micro Servo 9g - Tower Pro.2

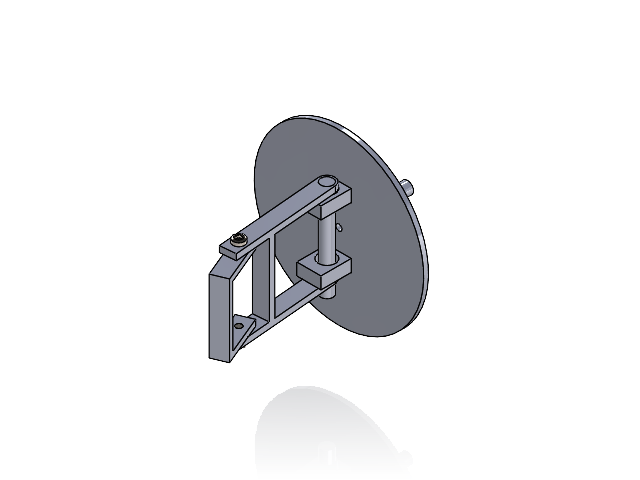
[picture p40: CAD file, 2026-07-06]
Mini robot/Système caméra/Schéma et Solidworks/solidwork bras/Assemblage bras.SLDASM
socle 1 x 2
cylindre racordement deux socles
bras 1 partie du dessous
bras 2 partie du dessus
Cercle
spur gear_iso x 2
Servo Motor MG996R
Servo Motor MG996R Hélice
socle pignon
hexalobular socket pan head_iso x 2

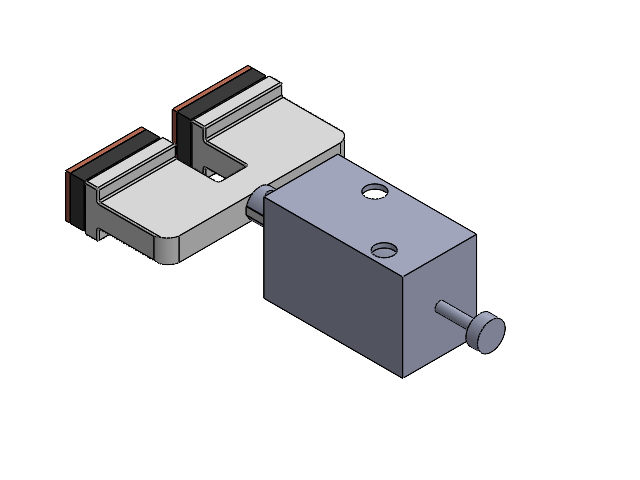
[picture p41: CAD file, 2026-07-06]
Station Hote/SolidWorks/Station hote/docking/Assemblage_final.SLDASM
axe solenoide
Cage moteur solénoide
support_ressort
Pièce2^Assemblage_final
cylindre interieur
bon_capuchon
ELECTRODE x 2
ISOLANT x 2

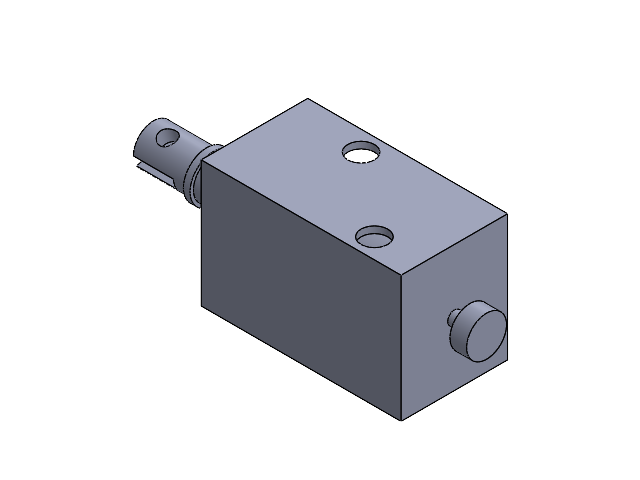
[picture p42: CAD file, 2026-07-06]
Station Hote/SolidWorks/Docking/Assemblage_moteur.SLDASM
Cage moteur solénoide
axe solenoide
cylindre interieur
support_ressort

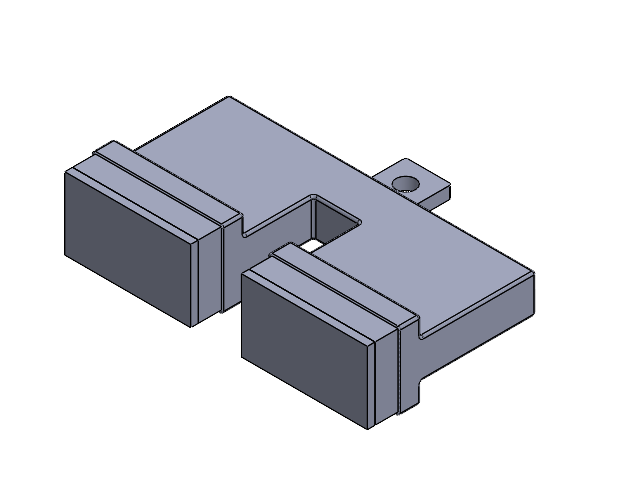
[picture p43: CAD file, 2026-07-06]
Station Hote/SolidWorks/Station hote/docking/assemblage capuchon.SLDASM
bon_capuchon
ELECTRODE x 2
ISOLANT x 2

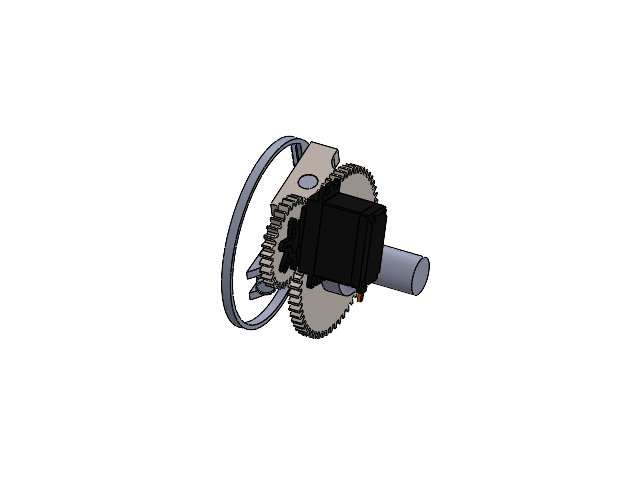
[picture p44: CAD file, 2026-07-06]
Mini robot/Système caméra/Schéma et Solidworks/Solidworks solution finale/Assemblage sol finale.SLDASM
Support Camera
Metric - Spur gear 1.5M 58T 14.5PA 6FW ---S58N75H50L8N
Camera MiniRobot
spur gear_iso
SG90 - Micro Servo 9g - Tower Pro.1
SG90 - Micro Servo 9g - Tower Pro.4
Pièce pivot avec la roue
Servo Motor MG996R
Servo Motor MG996R Hélice
Clapet anti-retour

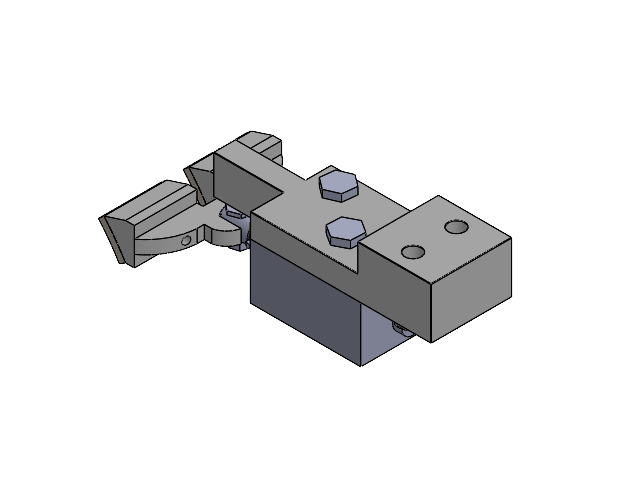
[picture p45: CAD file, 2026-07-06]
Station Hote/SolidWorks/Docking/Assemblage_final.SLDASM
axe solenoide
Cage moteur solénoide
support_ressort
Pièce2^Assemblage_final
cylindre interieur
bon_capuchon
Support solenoide docking
ELECTRODE x 2
Vis M4-8 x 2
Vis M2.5-9SLDPRT
Ecrou M2.5
pan head cross recess screw_iso x 2

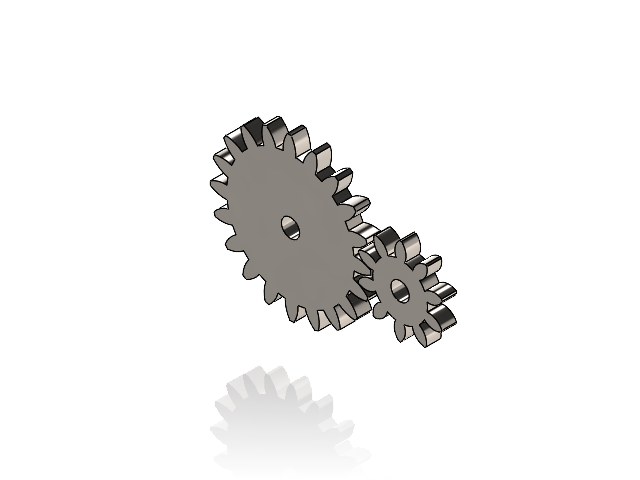
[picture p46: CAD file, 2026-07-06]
Mini robot/Système caméra/Schéma et Solidworks/solidwork bras/Assemblage engrenage 20 par 10.SLDASM
spur gear_iso x 2

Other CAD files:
Station Hote/SolidWorks/Docking/Assemblage_convertisseur.SLDASM
Station Hote/SolidWorks/Station hote/chassis/porte avec tôle.SLDASM
Station Hote/SolidWorks/Station hote/treuil/Assemblage Finale.SLDASM
Station Hote/SolidWorks/Station hote/treuil/Assemblage plaque ejection.SLDASM
Mini robot/Système caméra/Schéma et Solidworks/SOLIDWORKS MOTEUR/17HS08-1004S/17HS08-1004S.IGS
Mini robot/Système caméra/Schéma et Solidworks/SOLIDWORKS MOTEUR/17HS08-1004S/17HS08-1004S.SLDPRT
Mini robot/Système caméra/Schéma et Solidworks/SOLIDWORKS MOTEUR/17HS08-1004S/17HS08-1004S.STEP
Mini robot/Système caméra/Schéma et Solidworks/SOLIDWORKS PLAQUE/plaque de prototypage/DOTTED PCB 5 7 CM.SLDPRT
Mini robot/Système caméra/Schéma et Solidworks/Solidworks solution finale/Camera MiniRobot.SLDPRT
Mini robot/Système caméra/Schéma et Solidworks/Solidworks solution finale/Clapet anti-retour.SLDPRT
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

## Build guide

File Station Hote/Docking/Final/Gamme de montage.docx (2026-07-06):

NOM Système
N° étape | Opérations (soudure, taraudage, …) | Schéma, croquis, solidworks

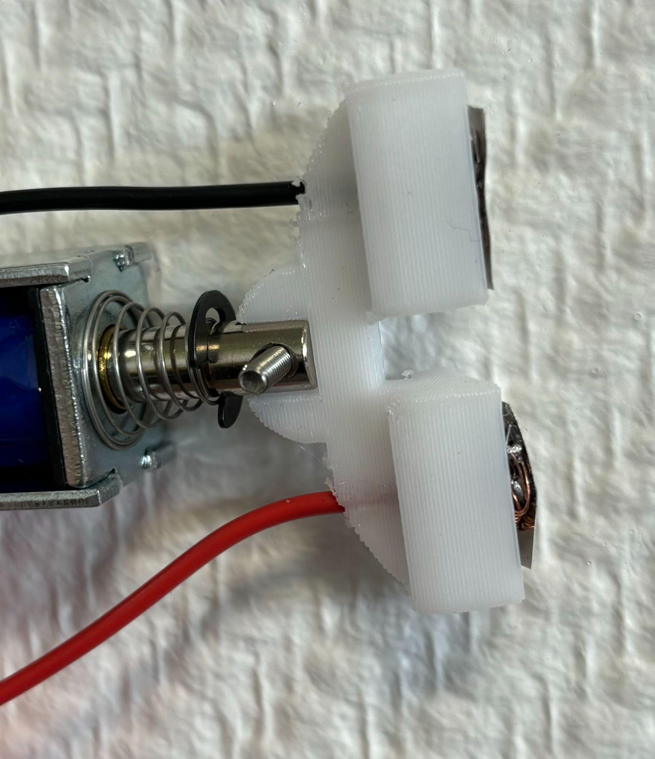
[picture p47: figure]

1 | Soudage des électrodes au support

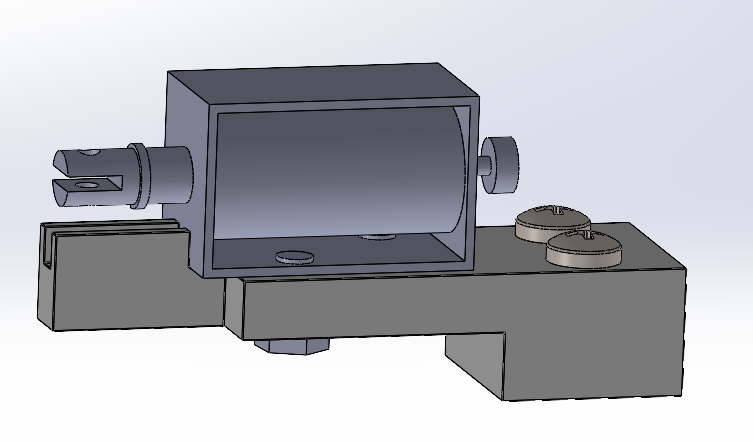
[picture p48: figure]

2 | Assemblage de la pièce support + guidage du solénoïde

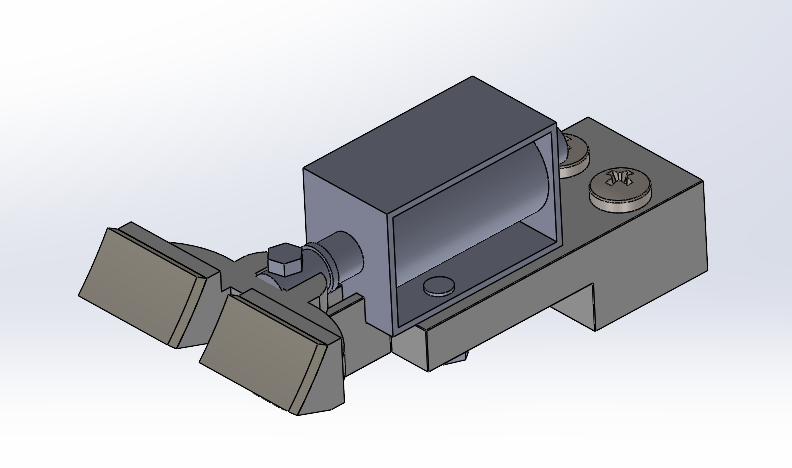
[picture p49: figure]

3 | Assemblage de tout le mécanisme en liaison avec le solénoïde


4 | Assemblage cc cv avec son support

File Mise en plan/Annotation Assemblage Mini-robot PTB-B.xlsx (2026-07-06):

Rep | Nb | Nom | Designatioin | Matière
1 | 1 | Chassis Bas |  | PETG
2 | 1 | Chassis Haut |  | PETG
3 | 1 | Moteur Pas à pas | Moteur pas à pas | Aluminium
4 | 1 | Plaque ( Support Moteur ) |  | PETG
5 | 1 | Pignon |  | PETG
6 | 1 | Batterie | Batterie lithium Ion 3S
7 | 1 | Couvercle Batterie |  | PETG
8 | 1 | Plaque de prototypage |  | Cuivre
9 | 1 | Servomoteur | Servomoteur FS90R | Plastique
10 | 1 | Couvercle clapet |  | PETG
11 | 1 | Roue |  | PETG
12 | 1 | Arduino nano | Arduino nano V3 | Plastique
13 | 1 | Module Camera ESP32 | ESP32-CAM-MB Micro USB | Plastique
14 | 3 | Pioins |  | PETG
15 | 1 | Bras |  | PETG
16 | 1 | Clapet |  | PETG
17 | 1 | charnière |  | Aluminium
18 | 1 | Hélice servomoteur |  | Plastique
19 | 1 | Circlip | Circlip Type Externe en Acier | Acier
20 | 1 | Roulement a bille | Roulement à billes à gorge profonde | Aluminium
21 | 4 | Vis | M3*5 | Acier
22 | 2 | Vis | M3WN | Acier
23 | 2 | Vis | M4*16 | Acier
24 | 6 | Vis | M3*4 | Acier
25 | 1 | AB abaisseur de tension | Convertisseur de tension 12V 5V | PETG

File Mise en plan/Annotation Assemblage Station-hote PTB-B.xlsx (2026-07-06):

Rep | nb | Nom | Désignation | Matière
1 | 1 | Pignon |  | PETG
2 | 1 | fixation arbre |  | PETG
3 | 1 | support axe |  | PETG
4 | 4 | Roulement | 6000-2RS-SKF | Aluminium
5 | 1 | Moteur | Polulu DC57 | Aluminium
6 | 1 | Arbre Usiné 1 |  | Aluminium
7 | 1 | Crabot 1 |  | PETG
8 | 1 | Crabot 2 |  | PETG
9 | 1 | Bobine |  | PETG
10 | 1 | Coffre Bobine |  | PETG
11 | 1 | Arbre Usiné 2 |  | Aluminium
12 | 1 | Roue denté |  | PETG
13 | 1 | Support arbre 2 |  | PETG
14 | 2 | Gachette |  | PETG
15 | 2 | Cale |  | PETG
16 | 2 | Goupille | GOUCYL01.5 | Acier
17 | 2 | Axe Gachette |  | Aluminium
18 | 2 | Axe moteur |  | Aluminium
19 | 4 | Support axe moteur |  | PETG
20 | 4 | Support motoreducteur |  | PETG
21 | 1 | Motoreducteur | WT341 | Aluminuim
22 | 2 | Raccord axe moteur |  | PETG
23 | 8 | Roulement a bille | MR85-2RS | Aluminium
24 | 16 | Vis | M5*20 | Acier
25 | 12 | Vis | M4*20 | Acier
26 | 2 | Axe moteur en translation |  | Aluminium
27 | 2 | Cylindre interieur |  | Aluminium
28 | 2 | Cage moteur a translation |  | Aluminium
29 | 1 | Capuchon |  | PETG
30 | 1 | Colle |  | PETG
31 | 1 | Electrode |  | Cuivre
32 | 1 | Anneau ejection |  | PETG
33 | 2 | Ressort de compression | T030-180-172L | Aluminium
34 | 28 | Equerre | BR20STS | Aluminium
35 | 4 | profilé 250 | Type I rainure 5 | Aluminium
36 | 9 | profilé 210 | Type I rainure 5 | Aluminium
37 | 56 | Vis | M4*8 | Aluminium
38 | 4 | Support axe ressort |  | PETG

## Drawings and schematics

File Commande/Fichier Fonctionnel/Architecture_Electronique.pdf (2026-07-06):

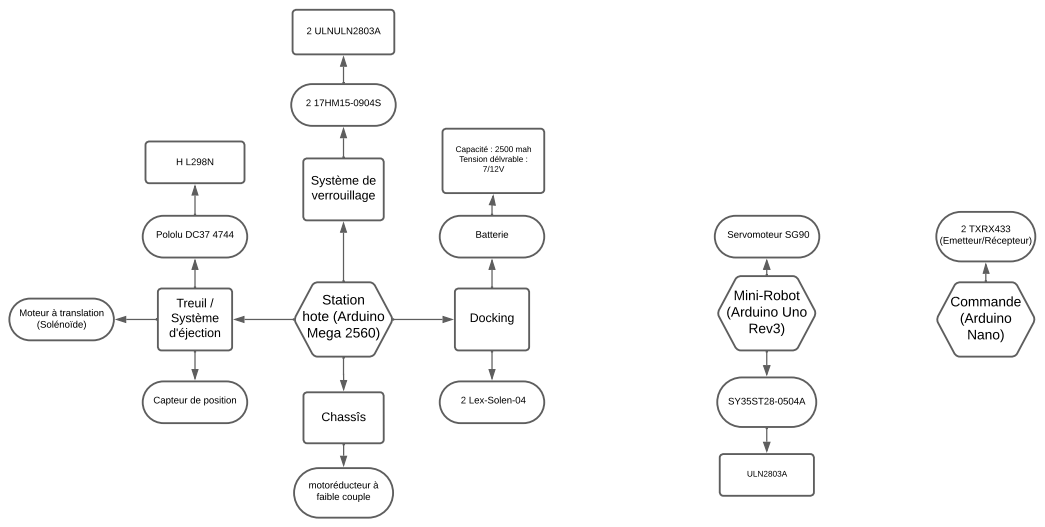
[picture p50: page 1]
Station hote (Arduino Mega 2560); Treuil / Système d'éjection; Système de verrouillage; Docking; Pololu DC37 4744; Moteur à translation (Solénoïde); Batterie; 2 Lex-Solen-04; Capacité : 2500 mah Tension délvrable : 7/12V; 2 ULNULN2803A; Mini-Robot (Arduino Uno Rev3); Servomoteur SG90; ULN2803A; Chassîs; motoréducteur à faible couple; Commande (Arduino Nano); 2 TXRX433 (Emetteur/Récepteur)

Capteur de position

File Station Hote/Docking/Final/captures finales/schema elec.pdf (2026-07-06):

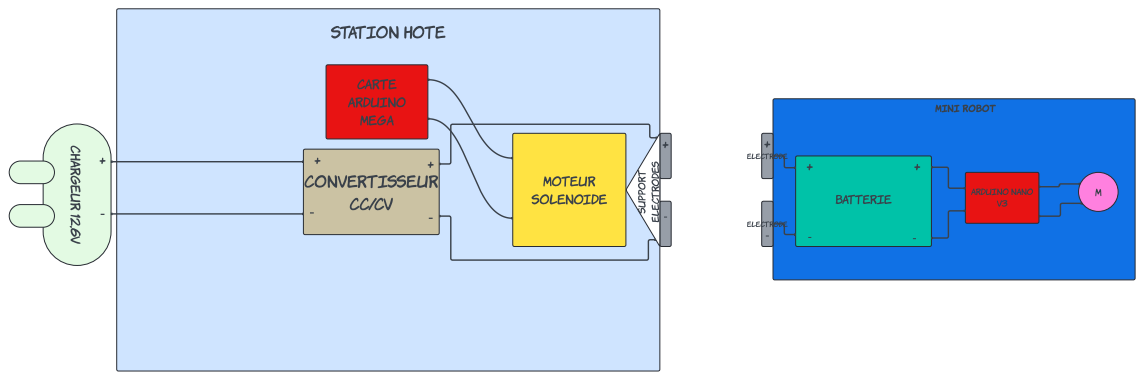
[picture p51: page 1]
BAT; STATI O; RTI S

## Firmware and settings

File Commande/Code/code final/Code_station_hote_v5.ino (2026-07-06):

const int stepPin = 13;
const int dirPin = 12;
const int nbre_steps=200;
#define borneENA        10      // On associe la borne "ENA" du L298N à la pin D10 de l'arduino
#define borneIN1        9       // On associe la borne "IN1" du L298N à la pin D9 de l'arduino
#define borneIN2        8       // On associe la borne "IN2" du L298N à la pin D8 de l'arduino
#define borneIN3        7       // On associe la borne "IN3" du L298N à la pin D7 de l'arduino
#define borneIN4        6       // On associe la borne "IN4" du L298N à la pin D6 de l'arduino
#define borneENB        5       // On associe la borne "ENB" du L298N à la pin D5 de l'arduino
#define borneENC        4
#define borneIN5        3
#define borneIN6        2

bool loopExecuted = false;

void setup() {
  pinMode(stepPin, OUTPUT);
  pinMode(dirPin, OUTPUT);
  pinMode(borneENA, OUTPUT);
  pinMode(borneIN1, OUTPUT);
  pinMode(borneIN2, OUTPUT);
  pinMode(borneIN3, OUTPUT);
  pinMode(borneIN4, OUTPUT);
  pinMode(borneENB, OUTPUT);
  pinMode(borneIN5, OUTPUT);
  pinMode(borneIN6, OUTPUT);
  pinMode(borneENC, OUTPUT);

  // Démarrage des moteurs
}

void loop() {
  if (!loopExecuted){ 
    ////On fait 2 pas pour eviter qu'il fasse n'importe quoi////
    digitalWrite(dirPin, HIGH); // oriente le moteur dans le sens horaire
 
    for (int i = 0; i < 2; i++) {
      digitalWrite(stepPin, HIGH);
      delayMicroseconds(100);
      digitalWrite(stepPin, LOW);
      delayMicroseconds(1000);
    }
    delay(100);
    //on active le pas à pas pour désengrener
    digitalWrite(dirPin, HIGH); // oriente le moteur dans le sens antihoraire
 
    for (int i = 0; i < 100; i++) {
      digitalWrite(stepPin, HIGH);
      delayMicroseconds(100);
      digitalWrite(stepPin, LOW);
      delayMicroseconds(1000);
    }
    delay(5000);

    /////On active les moteur du verrouaillage/////
    // Réglage des vitesses différentes pour les deux moteurs
    motorForward();
    setMotorSpeeds(250, 255);  // Vitesse pour moteur A et moteur B respectivement
    delay(220);               // Maintient la vitesse pendant 5 secondes

    // Arrête les moteurs après l'exécution
    motorStop();
    delay(2000);
    
    motorForward();
    setMotorSpeeds(250, 255);  // Vitesse pour moteur A et moteur B respectivement
    delay(28);

    motorStop();
    delay(5000);
    
    /////FIN PARTIE 1//////


    ////On fait le trucs pour etre sur que le crabaut engrene bien////
    for (int i = 0; i < 30; i++) {
      digitalWrite(stepPin, HIGH);
      delayMicroseconds(100);
      digitalWrite(stepPin, LOW);
      delayMicroseconds(1000);
    }

    digitalWrite(borneIN5, LOW);
    digitalWrite(borneIN6, HIGH);
    lancerRotationMoteurPontC();
 
    for (int i = 0; i < 70; i++) {
      digitalWrite(stepPin, HIGH);
      delayMicroseconds(100);
      digitalWrite(stepPin, LOW);
      delayMicroseconds(1000);
    }
    delay(5000);

    ////On fait tourner le pololu pour ramener le mini-robot////
    digitalWrite(borneIN5, LOW);
    digitalWrite(borneIN6, HIGH);
    lancerRotationMoteurPontC_2();
    delay(5000);

    ////On fait tourner le pololu dans l'autre sens pour donner du mou////
    digitalWrite(borneIN5, HIGH);
    digitalWrite(borneIN6, LOW);
    lancerRotationMoteurPontC_3();
    delay(5000);
    loopExecuted = true;
  }
}

void setMotorSpeeds(int speedA, int speedB) {
  // Limite les vitesses entre 0 et 255
  speedA = constrain(speedA, 0, 255);
  speedB = constrain(speedB, 0, 255);
  
  // Définit les vitesses pour les deux moteurs
  analogWrite(borneENA, speedA);
  analogWrite(borneENB, speedB);
}

void motorForward() {
  // Définit les moteurs pour tourner en avant
  digitalWrite(borneIN1, HIGH);
  digitalWrite(borneIN2, LOW);
  digitalWrite(borneIN3, HIGH);
  digitalWrite(borneIN4, LOW);
}

void motorBackward() {
  // Définit les moteurs pour tourner en arrière
  digitalWrite(borneIN1, LOW);
  digitalWrite(borneIN2, HIGH);
  digitalWrite(borneIN3, LOW);
  digitalWrite(borneIN4, HIGH);
}

void motorStop() {
  // Arrête les moteurs
  digitalWrite(borneIN1, LOW);
  digitalWrite(borneIN2, LOW);
  digitalWrite(borneIN3, LOW);
  digitalWrite(borneIN4, LOW);
}

void lancerRotationMoteurPontC() {
  digitalWrite(borneENC, HIGH);       
  delay(100);                        
  
  digitalWrite(borneENC, LOW);        
  delay(100);                        
}

void lancerRotationMoteurPontC_2() {
  digitalWrite(borneENC, HIGH);       
  delay(20000);                        
  
  digitalWrite(borneENC, LOW);        
  delay(1000);                        
}

void lancerRotationMoteurPontC_3() {
  digitalWrite(borneENC, HIGH);       
  delay(2500);                        
  
  digitalWrite(borneENC, LOW);        
  delay(1000);                        
}

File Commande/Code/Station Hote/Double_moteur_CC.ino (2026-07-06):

/*
   ______               _                  _///  _           _                   _
  /   _  \             (_)                |  __\| |         | |                 (_)
  |  [_|  |__  ___  ___ _  ___  _ __      | |__ | | ___  ___| |_ _ __ ___  _ __  _  ___  _   _  ___
  |   ___/ _ \| __|| __| |/ _ \| '_ \_____|  __|| |/ _ \/  _|  _| '__/   \| '_ \| |/   \| | | |/ _ \
  |  |  | ( ) |__ ||__ | | ( ) | | | |____| |__ | |  __/| (_| |_| | | (_) | | | | | (_) | |_| |  __/
  \__|   \__,_|___||___|_|\___/|_| [_|    \____/|_|\___|\____\__\_|  \___/|_| |_|_|\__  |\__,_|\___|
                                                                                      | |
                                                                                      \_|
  Fichier:      MarcheArretMoteurL298N
  Description:  Exemple de code Arduino, permettant de faire tourner un moteur à courant continu (marche avnat/marche arrière), via un module L298N branché sur un Arduino Uno
  Auteur:       Jérôme, Passion-Électronique (https://passionelectronique.fr/)
  Création :    05.05.2021
*/

//*******************************************************************************//
// Association des entrées du L298N, aux sorties utilisées sur notre Arduino Uno //
//*******************************************************************************//
#define borneENA        10      // On associe la borne "ENA" du L298N à la pin D10 de l'arduino
#define borneIN1        9       // On associe la borne "IN1" du L298N à la pin D9 de l'arduino
#define borneIN2        8       // On associe la borne "IN2" du L298N à la pin D8 de l'arduino
#define borneIN3        7       // On associe la borne "IN3" du L298N à la pin D7 de l'arduino
#define borneIN4        6       // On associe la borne "IN4" du L298N à la pin D6 de l'arduino
#define borneENB        5       // On associe la borne "ENB" du L298N à la pin D5 de l'arduino


//*******//
// SETUP //
//*******//
void setup() {
  
  // Configuration de toutes les pins de l'Arduino en "sortie" (car elles attaquent les entrées du module L298N)
  pinMode(borneENA, OUTPUT);
  pinMode(borneIN1, OUTPUT);
  pinMode(borneIN2, OUTPUT);
  pinMode(borneIN3, OUTPUT);
  pinMode(borneIN4, OUTPUT);
  pinMode(borneENB, OUTPUT);
}

//**************************//
// Boucle principale : LOOP //
//**************************//
void loop() {

  // Configuration du L298N en "marche avant", pour le moteur connecté au pont A. Selon sa table de vérité, il faut que :
  digitalWrite(borneIN1, HIGH);                 // L'entrée IN1 doit être au niveau haut
  digitalWrite(borneIN2, LOW);                  // L'entrée IN2 doit être au niveau bas

  // Et on lance le moteur (branché sur le pont A du L298N)
  lancerRotationMoteurPontA();

  // Puis on configure le L298N en "marche arrière", pour le moteur câblé sur le pont A. Selon sa table de vérité, il faut que :
  digitalWrite(borneIN1, LOW);                  // L'entrée IN1 doit être au niveau bas
  digitalWrite(borneIN2, HIGH);                 // L'entrée IN2 doit être au niveau haut

// Configuration du L298N en "marche avant", pour le moteur connecté au pont A. Selon sa table de vérité, il faut que :
  digitalWrite(borneIN3, HIGH);                 // L'entrée IN1 doit être au niveau haut
  digitalWrite(borneIN4, LOW);                  // L'entrée IN2 doit être au niveau bas

  // Et on lance le moteur (branché sur le pont A du L298N)
  lancerRotationMoteurPontA();

  // Puis on configure le L298N en "marche arrière", pour le moteur câblé sur le pont A. Selon sa table de vérité, il faut que :
  digitalWrite(borneIN3, LOW);                  // L'entrée IN1 doit être au niveau bas
  digitalWrite(borneIN4, HIGH);                 // L'entrée IN2 doit être au niveau haut

  // Et on relance le moteur (branché sur le pont A du L298N)
  lancerRotationMoteurPontA();
  
  // Puis... on boucle à l'infini !
}


//************************************************************************************//
// Fonction : lancerRotationMoteurPontA()                                             //
// But :      Active l'alimentation du moteur branché sur le pont A                   //
//            pendant 2 secondes, puis le met à l'arrêt (au moins 1 seconde)          //
//************************************************************************************//
void lancerRotationMoteurPontA() {
  digitalWrite(borneENA, HIGH);       // Active l'alimentation du moteur 1
  delay(2000);                        // et attend 2 secondes
  
  digitalWrite(borneENA, LOW);        // Désactive l'alimentation du moteur 1
  delay(1000);                        // et attend 1 seconde

  digitalWrite(borneENB, HIGH);       // Active l'alimentation du moteur 1
  delay(2000);                        // et attend 2 secondes
  
  digitalWrite(borneENB, LOW);        // Désactive l'alimentation du moteur 1
  delay(1000);                        // et attend 1 seconde
}
